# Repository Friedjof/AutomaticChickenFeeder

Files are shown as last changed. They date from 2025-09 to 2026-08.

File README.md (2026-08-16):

# 🐔 Automatic Chicken Feeder

> **Smart, battery-powered feeding system for your chickens with web-based scheduling and deep sleep power management**

An ESP32-C3 based automatic chicken feeder with RTC-scheduled feeding times, web configuration interface, and ultra-low power consumption. Perfect for keeping your chickens fed while you're away!

## 📸 Web Interface

| Schedule Configuration | Manual Control & Settings |
|:---:|:---:|
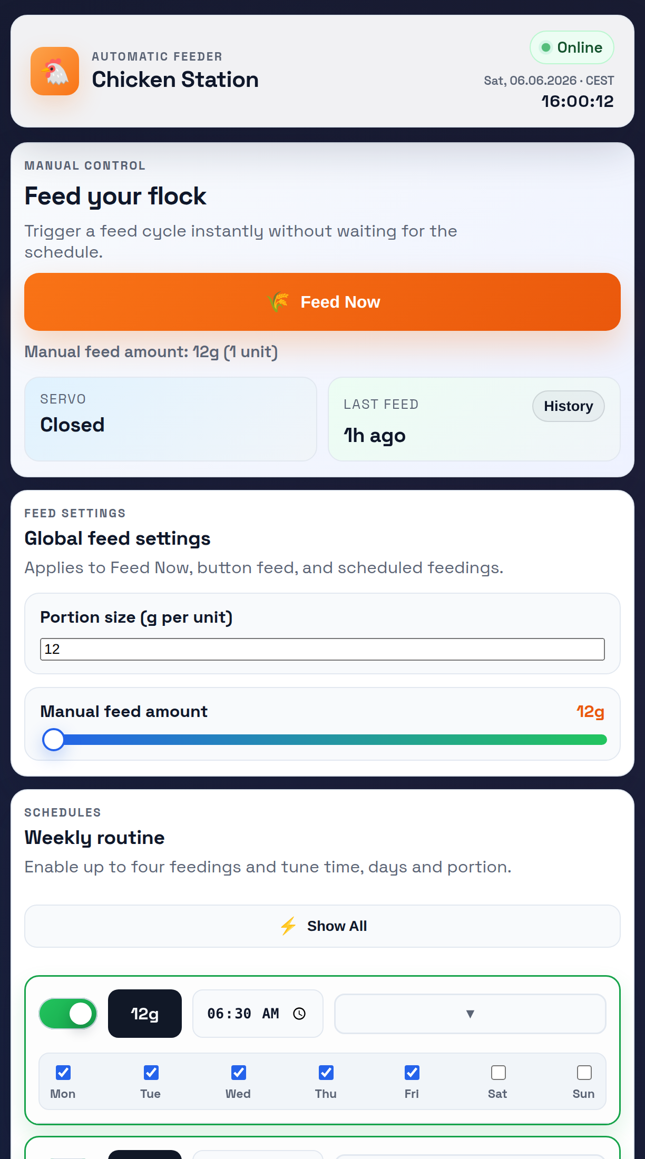
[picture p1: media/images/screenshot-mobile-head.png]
Schedule View
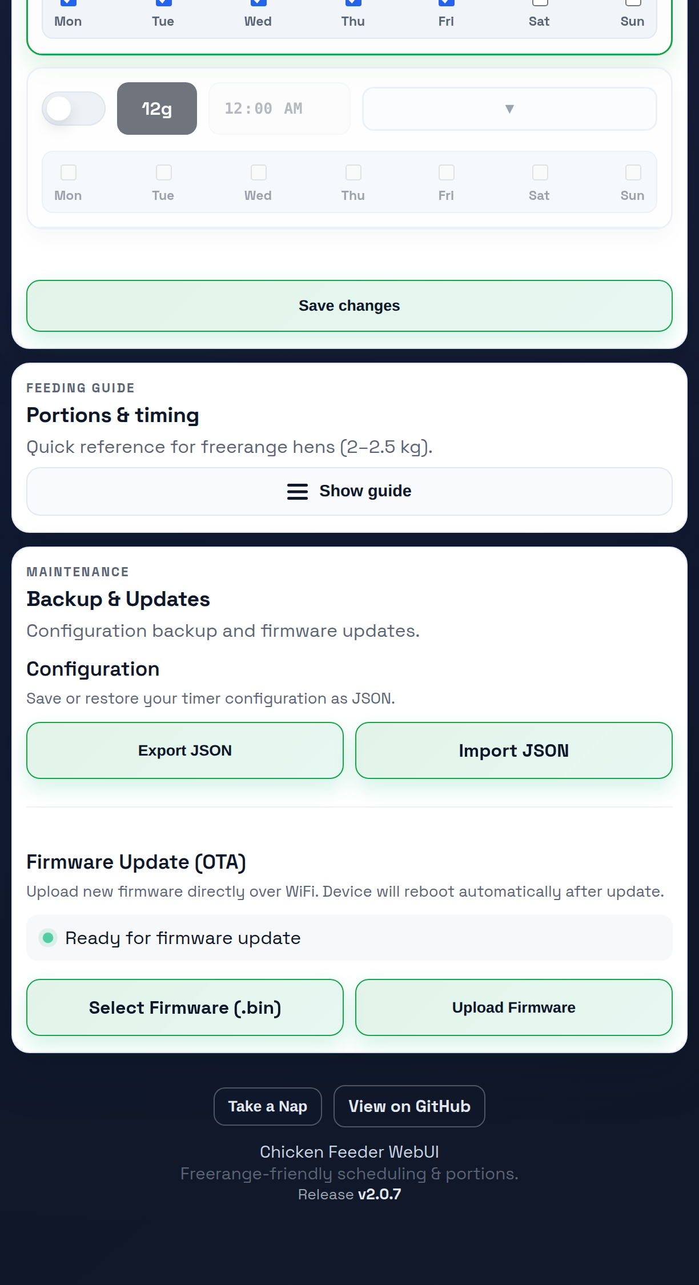
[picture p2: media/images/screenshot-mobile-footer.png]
Manual Control
|  |  |

## 🖨️ 3D Design

| Cross-Section | Animated View | Top View |
|:---:|:---:|:---:|
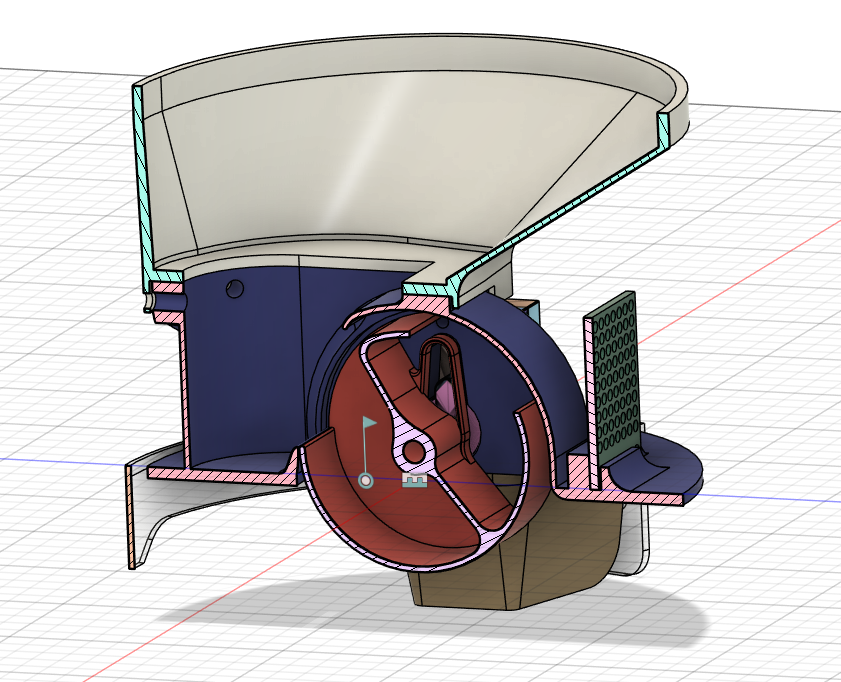
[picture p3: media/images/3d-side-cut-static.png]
Cross-Section
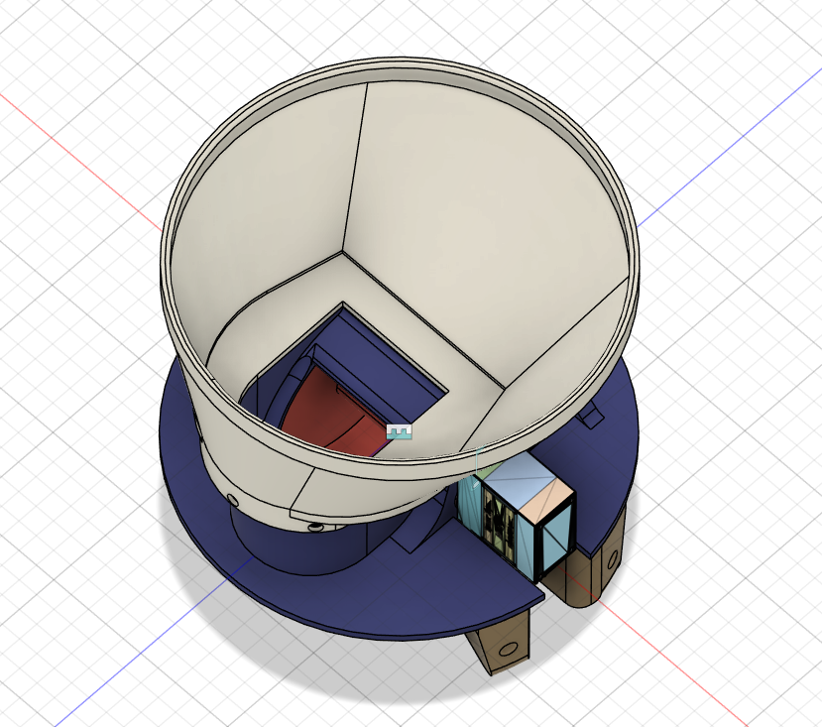
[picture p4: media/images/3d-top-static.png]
Top View
|  | 3D Animation |  |

> **Note:** 3D printable models (.stl files) will be added soon.

## ✨ Features

- 🕐 **RTC-Based Scheduling** - DS3231 external RTC with alarm interrupts for precise feeding times
- 📅 **Flexible Schedules** - Configure up to 6 feeding times with weekday selection (e.g., Mon-Fri only)
- 🌐 **Embedded Web Interface** - Complete configuration via WiFi AP, no SD card needed
- 📱 **Mobile-Optimized UI** - Smart View automatically shows relevant timers on mobile devices
- 🖥️ **Visible Device Clock** - Current device date/time shown in the top bar of the web UI
- 🔋 **Ultra-Low Power** - Deep sleep mode (~10-20µA) with dual wakeup sources
- ⚡ **Smart Power Management** - Automatic sleep after 2 minutes inactivity
- 🎚️ **Configurable Portions** - 1-5 portion units (12g per unit)
- 🔘 **Physical Button Control** - Single/double/long-press for manual operation
- 🕒 **Automatic Time Sync** - Browser syncs time to RTC when the web UI opens
- 🌍 **Timezone Support** - Europe/Berlin with CET/CEST daylight saving handling
- 🔄 **OTA Firmware Updates** - Update firmware over WiFi without USB cable

## 🎮 Button Controls

| Action | Function |
|---|---|
| **Single Click** | Start WiFi AP for configuration |
| **Double Click** | Manual feed (1 portion) |
| **Long Press** | Enter deep sleep immediately |
| **Press while sleeping** | Wake up + start AP mode (after 1s delay) |
| **Hold during boot** | Maintenance mode (optional, keeps WiFi on) |

## 🔧 Hardware Setup

### Components
- **Board:** Seeed Xiao ESP32-C3
- **RTC:** DS3231 external real-time clock module (I2C)
- **Servos:** 2x servo motors (GPIO2, GPIO21)
- **Button:** Push button with pull-up (GPIO4)
- **Power Control:** Transistor for servo power switching (GPIO5)

### GPIO Pin Assignment

| GPIO | Function | Direction | Notes |
|---|---|---|---|
| GPIO2 | Servo 2 | Output | PWM control |
| GPIO3 | RTC INT | Input (PULLUP) | Alarm wakeup |
| GPIO4 | Button | Input (PULLUP) | User input + wakeup |
| GPIO5 | Transistor | Output | Servo power control |
| GPIO10 | Vibration Motor | Output | Transistor-driven, anti-clump shaking |
| GPIO21 | Servo 1 | Output | PWM control |
| I2C SDA | DS3231 | I/O | RTC communication |
| I2C SCL | DS3231 | I/O | RTC communication |

### Power Requirements
- **ESP32-C3:** 3.3V
- **Servos:** 5V with adequate current (500mA+ peak)
- **RTC:** 3.3V or 5V (with built-in level shifting)

## 🚀 Quick Start

### Prerequisites
- PlatformIO Core (`pip install platformio`) or VS Code extension
- Node.js (v18+) for web interface build
- GNU Make
- ESP32-C3 connected via USB

### Build & Flash

**IMPORTANT:** Always use `make build` instead of `pio run` directly!

```bash
# Full build (web UI + firmware)
make build

# Flash to device
make flash

# Flash and monitor serial output
make run

# With specific port
make run 1        # Flash + monitor on /dev/ttyACM1
```

### Why Use the Makefile?

The Makefile automates the complete build pipeline:

1. **Web UI Build** - Runs `npm install` and Vite build
2. **Header Generation** - Converts HTML/CSS/JS to gzipped C headers
3. **Firmware Compilation** - Embeds web files into ESP32 firmware

**Skipping `make` and using `pio run` directly will result in outdated web files!**

### Device Port Management

```bash
# Auto-detect port (single device)
make flash
make monitor

# Specific port (multiple devices)
make flash 2      # Flash to /dev/ttyACM2
make monitor 2    # Monitor /dev/ttyACM2
make run 1        # Flash + monitor on /dev/ttyACM1

# List connected ESP32 devices
make list
```

## ⚙️ Configuration

### Web Interface Setup

1. **Power on the device** or **press button once** to start WiFi AP
2. **Connect to WiFi:** `ChickenFeeder` (no password)
3. **Open browser:** Navigate to `http://192.168.4.1`
4. **Configure schedules:**
   - Set feeding times (HH:MM format)
   - Select weekdays (Mon-Sun)
   - Set portion units (1-5)
   - Enable/disable schedules
5. **Save configuration** - Stored in ESP32 NVS (non-volatile storage)

### Manual Time Sync
Time syncs automatically from your browser when the web UI opens. The device clock shown in the top bar is loaded from the RTC once at startup and then advanced locally in the browser. Initial setup requires opening the web interface once to set the RTC time.

### Config Import/Export
Download or upload your configuration as JSON for backup or transfer to another device.

### OTA Firmware Updates

Update firmware wirelessly without USB connection:

1. **Start WiFi AP:**
   - Press button once (or device wakes from sleep)
   - Connect to WiFi: `ChickenFeeder` (no password)

2. **Open web interface:** Navigate to `http://192.168.4.1`

3. **Upload firmware:**
   - Scroll to "Maintenance" section at bottom
   - Click "Select Firmware (.bin)"
   - Choose your `.bin` file (from `.pio/build/esp32c3/firmware.bin`)
   - Click "Upload Firmware"
   - Wait for progress bar to complete (~10-30 seconds)

4. **Device reboots automatically** with new firmware

**Important:**
- Only upload `.bin` files built for ESP32-C3
- Do not power off during upload
- Configuration data is preserved (stored in NVS)
- Optionally backup your configuration before updating (Export JSON)

## 🔋 Power Management

### Deep Sleep Mode

The system enters deep sleep (~10-20µA) to conserve battery power:

- **After 2 minutes** of inactivity (no button press, no web client)
- **After RTC alarm** feeding completes
- **Manual trigger** via long-press button

### Wakeup Sources

| Source | GPIO | Trigger | Action |
|---|---|---|---|
| **Button** | GPIO4 | LOW | Wake → Wait ~150ms → Start AP |
| **RTC Alarm** | GPIO3 | LOW | Wake → Feed → Sleep |

### Stay-Awake Conditions
- WiFi AP has connected clients
- Feeding operation in progress
- Any button press (resets 2-minute timer)

### Battery Life Estimate

With a 2000mAh battery:
- **Deep sleep 23.5h/day:** ~11 years theoretical maximum
- **Realistic usage (30min active/day):** ~50 days

## 📁 Project Structure

```
AutomaticChickenFeeder/
├── src/
│   └── main.cpp                    # Main application
├── lib/
│   ├── ButtonService/              # Button input handling
│   ├── FeedingService/             # Dual servo control
│   ├── ClockService/               # DS3231 RTC management
│   ├── ConfigService/              # NVS configuration storage
│   ├── SchedulingService/          # Event queue & RTC alarms
│   └── WebService/                 # AsyncWebServer & captive portal
├── web/
│   ├── src/
│   │   ├── app.js                  # Web UI logic
│   │   └── styles.css              # Modern UI styling
│   ├── index.html                  # Main page
│   └── vite.config.js              # Build configuration
├── scripts/
│   └── web-to-header.py            # Converts web files to C headers
├── Makefile                        # Build automation
├── platformio.ini                  # PlatformIO configuration
└── AGENTS.md                       # Development guidelines

```

## 🛠️ Development

### Build Workflow

**After ANY code change (backend OR frontend):**
```bash
make build    # or just: make
```

**Frontend-only changes:**
```bash
make web-headers    # Rebuild web UI headers
pio run             # Compile firmware
```

**Backend-only changes:**
```bash
make build    # Still use make! Ensures web files are current
```

### Creating a Release

**Single command to create and publish a release:**
```bash
make release VERSION=v2.1.0
```

This will automatically:
- Update version in all files
- Rebuild web interface with new version
- Commit, tag, and push to GitHub
- Trigger automated release build

See [docs/RELEASE.md](docs/RELEASE.md) for details.

### Service Architecture

```
main.cpp
├── ButtonService (GPIO4)
│   ├── Single click → Start AP
│   ├── Double click → Manual feed
│   └── Long press → Deep sleep
├── FeedingService (GPIO2, GPIO21, GPIO5)
│   ├── Dual servo control
│   ├── Transistor power switching
│   └── Multi-portion feeding
├── ClockService (I2C @ 0x68)
│   ├── DS3231 RTC time management
│   ├── Timezone conversion (UTC → CET/CEST)
│   └── Alarm programming
├── ConfigService (NVS)
│   ├── 6 schedules storage
│   └── Portion unit configuration
├── SchedulingService
│   ├── Event queue (50 events, 7 days)
│   ├── Weekday mask filtering
│   └── RTC alarm management
└── WebService (WiFi AP)
    ├── AsyncWebServer (port 80)
    ├── Captive portal DNS
    ├── REST API endpoints
    └── Time sync (browser → RTC)
```

## 📚 Documentation

- **[AGENTS.md](AGENTS.md)** - Comprehensive development guidelines and build system documentation
- **[docs/dev.md](docs/dev.md)** - Development setup and troubleshooting

## 🤝 Contributing

1. Fork the repository
2. Create a feature branch
3. Make your changes
4. Test thoroughly (hardware + web interface)
5. Submit a pull request

## 📝 License

This project is open source. See LICENSE file for details.

## 🙏 Acknowledgments

Built with:
- [PlatformIO](https://platformio.org/) - Embedded development platform
- [ESP32Servo](https://github.com/madhephaestus/ESP32Servo) - Servo control library
- [Button2](https://github.com/LennartHennigs/Button2) - Button handling
- [RTClib](https://github.com/adafruit/RTClib) - DS3231 RTC library
- [ESPAsyncWebServer](https://github.com/me-no-dev/ESPAsyncWebServer) - Async web server
- [Vite](https://vitejs.dev/) - Frontend build tool

---

**Made with ❤️ for happy chickens** 🐔

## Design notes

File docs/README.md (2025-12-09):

# Automatic Chicken Feeder

This project is an **ESP32-C3 based automatic chicken feeder** using PlatformIO. It provides button-controlled servo operation to dispense chicken feed on demand.

## Features

- **Button Control**: Single click to trigger feeding cycle
- **Dual Servo System**: Two servos work in sync to open/close the feeding mechanism
- **Simple Operation**: Press button → servos open → 1 second delay → servos close
- **ESP32-C3**: Uses Seeed Xiao ESP32-C3 development board

## Hardware Requirements

- **Seeed Xiao ESP32-C3** development board
- **2x Servo Motors** (connected to GPIO pins 2 and 3)
- **Push Button** (connected to GPIO pin, defined in ButtonService)
- **Power Supply** suitable for servos

## Build & Flash

The Makefile supports convenient port selection for multiple ESP32 devices:

```bash
make                # build only
make flash          # flash with auto-detected port
make flash 1        # flash to /dev/ttyACM1
make monitor        # monitor with auto-detected port  
make monitor 2      # monitor /dev/ttyACM2
make run            # flash + monitor (auto-detect)
make run 1          # flash + monitor on /dev/ttyACM1
make list           # list available ESP32 devices with port numbers
make clean          # clean build artifacts
```

## Project Structure

- `platformio.ini` – ESP32-C3 configuration with Arduino framework
- `src/main.cpp` – Main application logic with button handling
- `lib/ButtonService/` – Button input handling using Button2 library
- `lib/FeedingService/` – Servo control for feeding mechanism
- `lib/WebService/` – (Placeholder for future web interface)
- `Makefile` – Enhanced build system with device port management

## How It Works

1. **Setup**: ButtonService initializes button with click handler, FeedingService attaches servos
2. **Main Loop**: Continuously checks for button presses
3. **Feed Cycle**: On button click → FeedingService.feed() → servos open (180°) → delay 1s → servos close (0°)
4. **Servo Coordination**: Two servos move in opposite directions for synchronized operation

## Dependencies

- `ESP32Servo` (v3.0.9+) - Servo motor control
- `Button2` (v2.5.0+) - Advanced button handling with debouncing

## Pin Configuration

- **Servo 1**: GPIO 3 (SERVO1_PIN)
- **Servo 2**: GPIO 2 (SERVO2_PIN)  
- **Button**: Defined in ButtonService (check ButtonService.hpp for pin)

## Usage

1. Power on the device
2. Press the button to trigger a feeding cycle
3. Servos will open, wait 1 second, then close
4. Repeat as needed for feeding chickens

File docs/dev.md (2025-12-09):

# Developer Notes

- **Toolchain**: PlatformIO + Arduino core for ESP32-C3 using standard espressif32 platform.
- **Hardware**: Seeed Xiao ESP32-C3 development board with 2 servos and button input.
- **Build Targets**: Enhanced Makefile with device port management:
  - `make` / `make build` – compile firmware for ESP32-C3.
  - `make flash` – flash with auto-detected port.
  - `make flash 1` – flash to specific port /dev/ttyACM1.
  - `make monitor` – serial monitor at 115200 baud (auto-detect port).
  - `make monitor 2` – monitor specific port /dev/ttyACM2.
  - `make run` – flash + monitor in one command (auto-detect).
  - `make run 1` – flash + monitor on /dev/ttyACM1.
  - `make list` – list available ESP32 devices with port numbers.
  - `make clean` – remove build artifacts.
- **Dependencies**: 
  - ESP32Servo library (v3.0.9+) for servo motor control
  - Button2 library (v2.5.0+) for advanced button handling
- **Pin Configuration**:
  - Servo 1: GPIO 3 (SERVO1_PIN)
  - Servo 2: GPIO 2 (SERVO2_PIN)
  - Button: Check ButtonService.hpp for pin definition
- **First Run**: If PlatformIO complains about missing Python in `.pio-home/penv`, create it with `python3 -m venv .pio-home/penv` once.

## Code Architecture

- **ButtonService**: Wraps Button2 library, handles single/double/long click events
- **FeedingService**: Controls dual servo system for feed dispensing mechanism
- **WebService**: Placeholder class for future web interface implementation
- **Main Loop**: Simple event-driven architecture with button → servo response

## Current Functionality

The project implements a basic chicken feeder with button-controlled servo operation:
1. Button press triggers feeding cycle
2. Two servos open synchronously (180° and 0° respectively) 
3. 1-second delay for feed dispensing
4. Servos close back to starting positions

This is a functional prototype, not a minimal "hello world" - it provides real chicken feeding capability.

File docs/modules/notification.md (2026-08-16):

# Notification Module (Optional)

> **Status:** Not implemented in the current firmware. This document describes a possible future module — there is no `lib/NotificationService` yet.

The notification module centralises how the feeder communicates alerts to the outside world. It is considered optional because the initial PlatformIO port can run without user-facing buzzers or LEDs, yet the architecture leaves space for future signalling features.

## Purpose
- Provide a single service interface for raising alerts (feeding errors, low battery, RTC issues, maintenance reminders).
- Abstract specific output hardware such as status LEDs, buzzers, or small displays so other services stay decoupled.
- Offer escalation logic (e.g. repeated beeps for unresolved faults) and quiet hours or acknowledgement handling once input buttons confirm an issue.

## Integration
- Receives events from the System Controller (e.g. `FeedCycleStarted`, `FeedCycleFailed`).
- Coordinates with the Power module to ensure notification hardware is powered only when needed.
- Optional bridge to the Web UI for surfacing alerts in the captive portal during active sessions.

## Future Work
- Define concrete output patterns (blink/beep sequences) per event severity.
- Add configuration hooks so farmers can mute or adjust notification intensity.
- Consider logging notifications to storage for troubleshooting once persistent telemetry is added.

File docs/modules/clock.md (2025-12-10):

# Clock Service

## Purpose
The ClockService wraps the DS3231 RTC module, providing accurate timekeeping, alarm management, and browser-based time synchronization.

## Hardware
- **DS3231 RTC**: High-precision I2C RTC with temperature compensation
- **I2C Bus**: SDA/SCL pins (board-specific)
- **Alarm Pin**: Interrupt output (GPIO 3)
- **Battery Backup**: CR2032 maintains time during power loss

## Responsibilities
- Initialize DS3231 via I2C
- Provide current time via `now()`
- Program hardware alarm for scheduled feeds
- Handle alarm interrupts and clear flags
- Sync time from browser timestamps
- Report RTC availability status

## Public API

```cpp
bool begin();                           // Initialize RTC
DateTime now();                         // Get current time
bool setTime(const DateTime &dt);      // Set RTC time
bool setAlarm(const DateTime &dt);     // Program alarm
bool clearAlarm();                      // Disable and clear alarm
bool checkAlarmFlag();                  // Check if alarm triggered
bool isAvailable() const;               // RTC connection status
```

## RTC Initialization

```cpp
bool ClockService::begin()
```

1. Initialize I2C bus
2. Detect DS3231 presence
3. Check if RTC lost power
4. If lost power: mark as requires sync
5. Disable alarm by default
6. Return availability status

## Time Management

### Getting Current Time
```cpp
DateTime now()
```

- Returns current time from DS3231
- DateTime format: year, month, day, hour, minute, second
- Unix timestamp available via `dt.unixtime()`
- Returns invalid DateTime if RTC unavailable

### Setting Time
```cpp
bool setTime(const DateTime &dt)
```

- Writes new time to DS3231
- Called by browser sync endpoint
- Validates DateTime before write
- Returns success/failure

## Alarm Management

### Programming Alarm
```cpp
bool setAlarm(const DateTime &dt)
```

1. Disables existing alarm
2. Calculates alarm registers from DateTime
3. Programs DS3231 Alarm 1
4. Enables alarm interrupt
5. Logs alarm time to serial
6. Returns success/failure

**DS3231 Alarm Capabilities:**
- Alarm 1: Seconds, minutes, hours, day/date
- Alarm 2: Minutes, hours, day/date (not used)
- Single alarm active at a time

### Clearing Alarm
```cpp
bool clearAlarm()
```

1. Clears alarm flag (`rtc.clearAlarm(1)`)
2. Disables alarm (`rtc.disableAlarm(1)`)
3. Logs to serial: "[CLOCK] Alarm cleared"
4. Called when no schedules active

### Checking Alarm Status
```cpp
bool checkAlarmFlag()
```

- Returns `rtc.alarmFired(1)`
- Called in main loop via SchedulingService
- True if alarm interrupt triggered

## Browser Time Sync

Triggered via WebService API: `POST /api/time`

### Sync Flow
1. Browser sends ISO timestamp
2. WebService parses to Unix timestamp
3. ClockService converts to DateTime
4. `setTime()` updates DS3231
5. Logs sync event to serial

### Format
- Input: ISO 8601 string ("2025-01-15T14:30:00Z")
- Converted to DateTime
- Written to DS3231 registers

## Deep Sleep Integration

### Before Sleep
- RTC alarm remains programmed in DS3231 hardware
- DS3231 maintains time on battery backup
- Alarm pin stays configured as interrupt source

### On Wake
- ESP32 wakes from GPIO interrupt (RTC_INT_PIN)
- SchedulingService calls `checkAlarmFlag()`
- ClockService confirms alarm triggered
- Alarm cleared via `clearAlarm()`

## Integration Points

### SchedulingService
- Calls `now()` for event generation
- Programs alarms via `setAlarm()`
- Checks alarm status via `checkAlarmFlag()`
- Clears alarms via `clearAlarm()`

### FeedingService
- Gets timestamps for feed history
- Calls `now()` via `recordFeedEvent()`

### WebService
- Receives browser time sync requests
- Formats DateTime to ISO 8601 strings
- Returns RTC status in API responses

### Main Application
- Calls `begin()` during setup
- Logs availability status

## Error Handling

### RTC Unavailable
- `begin()` returns false
- `available` flag set to false
- All operations return failure
- System continues without RTC (no scheduled feeds)
- Logged as "[WARN] DS3231 RTC not available"

### Lost Power
- Detected during `begin()`
- Logged as "[CLOCK] RTC lost power, time may be invalid"
- Requires browser sync to restore accurate time

### Invalid DateTime
- Validation before RTC writes
- Returns false on invalid input
- Logs error to serial

## Logging
All operations log to serial with `[CLOCK]` prefix:
- Initialization status
- Lost power detection
- Time sync events
- Alarm programming
- Alarm clearing
- Error conditions

## Testing

### Manual Testing
1. Power cycle device → check for lost power detection
2. Set alarm 2 minutes in future via schedule
3. Monitor serial for alarm programming
4. Wait for alarm trigger
5. Verify alarm flag set and cleared

### Browser Sync Testing
1. Open web UI
2. Monitor serial for sync logs
3. Verify time matches browser
4. Check RTC persists after power cycle

### Alarm Testing
1. Program alarm via SchedulingService
2. Enter deep sleep
3. Wake on RTC alarm
4. Verify alarm flag cleared
5. Check next alarm programmed

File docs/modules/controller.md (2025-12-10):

# Main Controller (main.cpp)

## Purpose
The main.cpp file coordinates all services, manages the application lifecycle, handles wake/sleep logic, and implements the main loop.

## Architecture
Simple procedural design with direct service instantiation:
- No abstract interfaces or event bus
- Services communicate via direct method calls
- State managed through function calls and flags

## Services

### Instantiation
```cpp
ButtonService buttonService;
FeedingService feedingService;
ClockService clockService;
ConfigService configService;
SchedulingService schedulingService(configService, clockService, feedingService);
WebService webService(configService, clockService, feedingService, schedulingService);
```

### Initialization Order (setup())
1. **ConfigService**: Initialize NVS, load settings
2. **ClockService**: Initialize RTC, check time validity
3. **Feed History**: Load from NVS into FeedingService
4. **ButtonService**: Setup GPIO, attach handlers
5. **FeedingService**: Configure servo pins, set clock reference
6. **SchedulingService**: Generate events, program first alarm
7. **WebService**: Prepare server (doesn't start until AP active)

## Hardware Configuration

### Pin Definitions
```cpp
#define RTC_INT_PIN 3      // DS3231 alarm interrupt
#define BUTTON_PIN 4       // User button
#define SERVO1_PIN 21      // Dispenser servo 1
#define SERVO2_PIN 2       // Dispenser servo 2
#define TRANSISTOR_PIN 5   // Servo power control
```

### Wake Sources
- **RTC Alarm**: GPIO 3 (scheduled feeds)
- **Button**: GPIO 4 (manual control, AP activation)

## State Flags

```cpp
bool wokeFromRtcAlarm = false;   // Woke from scheduled alarm
bool wokeFromButton = false;      // Woke from button press
unsigned long lastActivityMillis; // Last user/system activity
unsigned long ignoreButtonUntil;  // Button debounce after wake
```

## Boot Sequence

### Wake Cause Detection
```cpp
esp_sleep_wakeup_cause_t wakeupReason = esp_sleep_get_wakeup_cause();
uint64_t gpioStatus = esp_sleep_get_gpio_wakeup_status();
```

**Wake Reasons:**
- `ESP_SLEEP_WAKEUP_GPIO`: RTC alarm or button
- Other: Power-on reset or unknown

### Maintenance Mode
- Hold button during boot
- Logged as `[MAINTENANCE]`
- Features:
  - Persistent AP (no timeout)
  - OTA updates enabled
  - No automatic sleep
  - Infinite loop serving web UI

### Normal Boot Flow
1. Detect wake cause
2. Initialize all services
3. Load feed history
4. Handle wake-specific actions:
   - **RTC Alarm**: Process due schedules immediately
   - **Button**: Start AP after 2s delay
5. Enter main loop

## Main Loop

```cpp
void loop() {
    buttonService.loop();
    feedingService.update();
    webService.update();
    schedulingService.update();
    handleSleepLogic();
}
```

### Service Updates
- **ButtonService**: Poll button state, trigger callbacks
- **FeedingService**: Advance state machine, complete feeds
- **WebService**: Process DNS, check AP timeout
- **SchedulingService**: Check RTC alarm flag

### Sleep Logic
```cpp
void handleSleepLogic()
```

**Conditions preventing sleep:**
- Feeding in progress
- AP active
- Recent activity (< 2 minutes)

**Automatic sleep triggers:**
- RTC alarm completed (return to sleep immediately)
- Inactivity timeout (2 minutes)

## Button Handlers

### Single Click
```cpp
void simpleClickHandler(Button2 &btn)
```

- Starts AP mode
- Resets activity timer
- 2-second ignore window after wake

### Double Click
```cpp
void doubleClickHandler(Button2 &btn)
```

- Triggers manual feed (1 portion)
- Resets activity timer
- 2-second ignore window after wake

### Long Press
```cpp
void longClickHandler(Button2 &btn)
```

- Enters deep sleep immediately
- No ignore window (always active)

## Deep Sleep Management

### Entering Sleep
```cpp
void enterDeepSleep(const char* reason)
```

1. Save feed history to NVS
2. Stop AP if active
3. Configure wake sources (RTC + Button)
4. Enable GPIO wake on LOW signal
5. Log reason and enter deep sleep

**Wake Mask:**
```cpp
const uint64_t wakeMask = (1ULL << RTC_INT_PIN) | (1ULL << BUTTON_PIN);
esp_deep_sleep_enable_gpio_wakeup(wakeMask, ESP_GPIO_WAKEUP_GPIO_LOW);
```

### Sleep Triggers
- "RTC alarm handled" (after feed completed)
- "Inactivity timeout" (2 minutes idle)
- "Manual long press" (user requested)
- "Remote request" (via WebService)

## Activity Tracking

### Mark Activity
```cpp
void markActivity()
```

- Updates `lastActivityMillis`
- Called on:
  - Button presses
  - Feeding operations
  - Web UI interactions (via WebService)

### Inactivity Timeout
- `INACTIVITY_SLEEP_MS`: 120000 (2 minutes)
- Compared against max of `lastActivityMillis` and web client activity
- Triggers automatic sleep

## Feed History Persistence

### Load (setup)
```cpp
FeedHistoryEntry history[MAX_FEED_HISTORY];
uint8_t historyCount = configService.loadFeedHistory(history, MAX_FEED_HISTORY);
feedingService.loadFeedHistory(history, historyCount);
```

### Save (before sleep)
```cpp
configService.saveFeedHistory(feedingService.getFeedHistory(),
                               feedingService.getFeedHistoryCount());
```

## Power Management Strategy

### Active Time Minimization
- Sleep between scheduled feeds
- AP only active when needed
- Servo power only during dispense
- WiFi disabled in sleep

### Wake/Sleep Cycle
1. **Wake** (RTC or button)
2. **Execute** (feed or serve UI)
3. **Sleep** (automatic after completion)

Typical cycle: <30 seconds active, hours sleeping

## Error Handling

### Service Init Failures
- Logged to serial with `[ERROR]` prefix
- System continues with reduced functionality
- Example: RTC unavailable → no scheduled feeds, manual still works

### Watchdog
- No explicit watchdog (relies on ESP32 default)
- Feeding timeout prevents servo lockup
- AP timeout prevents battery drain

## Logging

All major events logged to serial (115200 baud):
- `[INFO]`: Normal operations
- `[WARN]`: Recoverable issues
- `[ERROR]`: Critical failures
- `[DEBUG]`: Detailed state info
- Service-specific: `[BUTTON]`, `[SCHED]`, `[WEB]`, `[CLOCK]`, `[CONFIG]`

## Testing

### Boot Testing
1. Power on → cold boot
2. Hold button → maintenance mode
3. RTC wake → alarm execution
4. Button wake → AP activation

### Sleep Testing
1. Manual feed → auto sleep after 2 min
2. Long press → immediate sleep
3. RTC alarm → execute and return to sleep
4. AP timeout → auto sleep after 60s

### Integration Testing
1. Schedule feed → verify RTC alarm → wake and feed
2. Manual feed → verify history saved
3. Config change → verify alarm reprogrammed
4. Factory reset → verify defaults restored

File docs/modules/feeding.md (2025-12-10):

# Feeding Service

## Purpose
The FeedingService controls the dual-servo dispensing mechanism. It manages the complete feed cycle including power control, servo movement, timing sequences, and feed event tracking.

## Hardware
- **ESP32-C3** (Seeed XIAO ESP32C3)
- **Servo 1 & 2**: Controlled via ESP32Servo library
- **Transistor**: MOSFET for servo power management (GPIO 5)
- **DS3231 RTC**: For timestamp tracking

## Responsibilities
- Execute feed cycles with configurable portion counts (1-5 units)
- Manage servo power via transistor to minimize energy consumption
- Implement state machine for deterministic servo sequencing
- Track feed events with timestamps for history
- Provide feed status to other services

## State Machine

### States
1. **IDLE**: Servos powered down, waiting for feed request
2. **POWER_ON**: Transistor enabled, waiting for servo voltage stabilization
3. **ATTACH_SERVOS**: Servos attached to PWM pins
4. **SERVO_READY**: Servos ready, preparing for movement
5. **MOVING**: Servos executing open/close sequence
6. **DETACH_SERVOS**: Servos detached from PWM
7. **POWER_OFF**: Transistor disabled, servos unpowered
8. **FEED_WAITING**: Waiting between open/close cycles for multi-portion feeds

### Timing Constants
- `POWER_ON_DELAY`: 100ms - Servo power stabilization
- `SERVO_ATTACH_DELAY`: 100ms - Time after attach before movement
- `SERVO_MOVE_TIME`: 620ms - Duration for servo movement completion
- `FEED_WAIT_TIME`: 1000ms - Delay between open and close

## Feed Cycle Flow

### Single Portion
1. User/Timer triggers `feed(1)`
2. State: IDLE → POWER_ON (enable transistor)
3. State: POWER_ON → ATTACH_SERVOS (attach servos at 100ms)
4. State: ATTACH_SERVOS → SERVO_READY (servos write target position immediately)
5. State: SERVO_READY → MOVING (wait for stabilization)
6. State: MOVING → DETACH_SERVOS (after 620ms movement time)
7. State: DETACH_SERVOS → POWER_OFF (detach servos)
8. State: POWER_OFF → IDLE (disable transistor, record feed event)

### Multiple Portions
For `feed(count > 1)`, the cycle repeats:
- Open gate → Wait → Close gate → Wait → Open gate (next portion)
- After final portion, system returns to IDLE
- Single feed event recorded with total portion count

## Feed History Tracking

### Recording
- Every feed completion calls `recordFeedEvent()`
- Stores: Unix timestamp + portion_units
- Maintains ring buffer of last 10 feeds in RAM
- Persisted to NVS before deep sleep

### Storage
- Ring buffer: `FeedHistoryEntry feedHistory[10]`
- Tracked via: `feedHistoryCount` and `feedHistoryIndex`
- Circular overwrite of oldest entry when full

## Public API

```cpp
void feed(uint8_t count = 1);              // Trigger feed with 1-5 portions
void update();                              // Must be called in loop()
bool isFeeding();                           // Check if feed in progress
uint8_t getPosition();                      // Get current servo position (0-180)
uint32_t getLastFeedTimestamp();            // Unix timestamp of last feed

// Feed history management
void addFeedToHistory(uint32_t timestamp, uint8_t portionUnits);
uint8_t getFeedHistoryCount() const;
const FeedHistoryEntry* getFeedHistory() const;
void loadFeedHistory(const FeedHistoryEntry* history, uint8_t count);
void clearFeedHistory();

void setClockService(ClockService* clock);  // Required for timestamps
```

## Servo Configuration
- **Servo1**: Inverted position `SERVO_MAX_ANGLE - targetPosition`
- **Servo2**: Direct position `targetPosition`
- **Range**: 0° (closed) to 180° (open)
- **PWM Range**: 500-2400μs

## Power Management
- Servos only powered during active feed cycles
- Transistor (GPIO 5) controls power rail
- Automatic power-off after each cycle completes
- Prevents unnecessary battery drain

## Integration Points

### ClockService
- Required for timestamp generation
- Set via `setClockService(ClockService*)` during setup
- Used by `recordFeedEvent()` to get current time

### ConfigService
- Provides portion unit grams configuration
- Loads/saves feed history to NVS

### SchedulingService
- Calls `feed(portionUnits)` when scheduled event triggers
- Monitors `isFeeding()` to prevent sleep during operation

### WebService
- Exposes feed history via `/api/status/history`
- Triggers manual feeds via `/api/feed` endpoint

## Safety Features
- Single feed request guard: ignores requests while feeding
- Portion count validation: clamped to 1-5 range
- State machine prevents power glitches
- Servo detach before power-off prevents brown-out

## Testing
- Manual feed via double-click button
- API endpoint: `POST /api/feed`
- Monitor serial output for state transitions
- Verify feed history via `GET /api/status/history?limit=10`

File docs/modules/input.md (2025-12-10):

# Button Service (Input)

## Purpose
The ButtonService handles the single physical button interface, providing debounced input detection and multi-gesture recognition (single click, double click, long press).

## Hardware
- **Button Pin**: GPIO 4
- **Type**: Active-LOW with internal pull-up
- **Library**: Button2 (gesture recognition)

## Responsibilities
- Initialize button GPIO with pull-up
- Detect button gestures (single, double, long press)
- Provide callback registration for main application
- Handle button debouncing automatically
- Support wake-from-sleep button handling

## Button Gestures

### Single Click
- **Action**: Start WiFi Access Point
- **Use Case**: Open web UI for configuration
- **Callback**: `setSimpleClickHandler()`
- **Debounce**: 2-second ignore window after wake

### Double Click
- **Action**: Trigger manual feed (1 portion)
- **Use Case**: Quick feeding without UI
- **Callback**: `setDoubleClickHandler()`
- **Debounce**: 2-second ignore window after wake

### Long Press
- **Action**: Enter deep sleep immediately
- **Use Case**: Manual power down
- **Callback**: `setLongClickHandler()`
- **No Debounce**: Always active (override safety)

## Public API

```cpp
void begin();                                         // Initialize button
void loop();                                          // Must be called in loop()
void setSimpleClickHandler(void (*callback)(Button2&));
void setDoubleClickHandler(void (*callback)(Button2&));
void setLongClickHandler(void (*callback)(Button2&));
```

## Initialization

```cpp
void ButtonService::begin()
```

1. Configure Button2 library
2. Set GPIO 4 as input with pull-up
3. Register click handlers
4. Log initialization

## Main Loop

```cpp
void ButtonService::loop()
```

- Calls `button.loop()` from Button2 library
- Handles debouncing and gesture detection
- Triggers registered callbacks on events

## Wake Handling

### Wake Detection
In main.cpp:
```cpp
if (wokeFromButton) {
    ignoreButtonUntil = millis() + 2000;  // 2-second ignore window
}
```

### Button Ignore Logic
```cpp
if (millis() < ignoreButtonUntil) {
    Serial.println("[BUTTON] Ignoring click (too soon after wakeup)");
    return;  // But still mark activity
}
```

**Purpose**: Prevent consuming the wakeup button press as an action

## Callback Implementations (main.cpp)

### Single Click Handler
```cpp
void simpleClickHandler(Button2 &btn) {
    markActivity();
    if (millis() < ignoreButtonUntil) return;

    Serial.println("[BUTTON] Single click - Starting AP mode");
    webService.startAP("ChickenFeeder", "");
}
```

### Double Click Handler
```cpp
void doubleClickHandler(Button2 &btn) {
    markActivity();
    if (millis() < ignoreButtonUntil) return;

    Serial.println("[BUTTON] Double click - Manual feed");
    feedingService.feed(1);
}
```

### Long Press Handler
```cpp
void longClickHandler(Button2 &btn) {
    Serial.println("[BUTTON] Long click - Entering deep sleep");
    enterDeepSleep("Manual long press");
}
```

**Note**: Long press has no ignore window - always processes

## Maintenance Mode Detection

In main.cpp setup():
```cpp
pinMode(BUTTON_PIN, INPUT_PULLUP);
delay(50);  // Debounce
bool maintenanceModeRequested = (digitalRead(BUTTON_PIN) == LOW);
```

If button held during boot:
- Enter maintenance mode
- Persistent AP with OTA enabled
- No automatic sleep
- Infinite loop serving web UI

## Integration Points

### Main Application
- Registers callback handlers during setup
- Implements ignore window logic
- Calls `loop()` in main loop
- Marks activity on button events

### WebService
- Started via single-click callback
- AP mode activated for configuration

### FeedingService
- Triggered via double-click callback
- Executes 1-portion feed

### Power Management
- Long press triggers immediate deep sleep
- Button wake prevents timeout sleep
- Activity tracking resets sleep timer

## Button2 Library Features

### Automatic Handling
- Hardware debouncing
- Click counting (single/double)
- Long press timing
- Event callbacks

### Timing Thresholds
- Click timeout: ~400ms
- Long press threshold: ~1000ms
- Double click window: ~400ms

(Library defaults, not explicitly configured)

## Wake Source Configuration

In main.cpp before sleep:
```cpp
const uint64_t wakeMask = (1ULL << RTC_INT_PIN) | (1ULL << BUTTON_PIN);
esp_deep_sleep_enable_gpio_wakeup(wakeMask, ESP_GPIO_WAKEUP_GPIO_LOW);
```

**Wake Trigger**: LOW signal (button pressed)

## Safety Features

### Click Debouncing
- Hardware debounce via Button2
- Software ignore window after wake
- Prevents accidental double-triggers

### Activity Marking
- All button events mark activity
- Resets sleep timeout
- Keeps system awake during interaction

### Long Press Override
- No ignore window on long press
- Allows emergency sleep from any state
- User can force sleep if system stuck

## Testing

### Gesture Testing
1. Single click → verify AP starts
2. Double click → verify feed triggers
3. Long press → verify immediate sleep
4. Test ignore window: press immediately after wake

### Wake Testing
1. Sleep device
2. Press button → verify wake
3. Verify 2-second ignore window active
4. Test that third press triggers action

### Maintenance Mode
1. Hold button during power-on
2. Verify persistent AP starts
3. Check maintenance mode logs

## Logging
All button events logged with `[BUTTON]` prefix:
- Click type (single/double/long)
- Action taken
- Ignore window status
- Activity marking

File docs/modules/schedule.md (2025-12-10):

# Scheduling Service

## Purpose
The SchedulingService manages the feeding schedule by generating timer events from configured schedules, programming RTC alarms, and triggering feeds at the appropriate times.

## Responsibilities
- Generate timer events from enabled schedules
- Program DS3231 RTC alarm for next due event
- Handle RTC alarm interrupts and execute feeds
- Regenerate events when configuration changes
- Maintain event queue for upcoming feeds

## Hardware
- **DS3231 RTC**: Hardware alarm capability
- **RTC Interrupt Pin** (GPIO 3): Wakes ESP32 from deep sleep
- Event generation covers next 7 days

## Data Structures

### Timer Event
```cpp
struct TimerEvent {
    DateTime timestamp;    // When feed should occur
    uint8_t scheduleId;   // Which schedule triggered this (1-6)
    uint8_t portionUnits; // How many portions to dispense
    bool valid;           // Event is active
};
```

### Schedule Entry
```cpp
struct Schedule {
    uint8_t id;              // 1-6
    bool enabled;            // Active/inactive
    char time[6];            // "HH:MM" format
    uint8_t weekday_mask;    // Bit 0=Sunday, 6=Saturday
    uint8_t portion_units;   // 1-5 units per feed
};
```

## Public API

```cpp
void begin();              // Initialize, generate events, program first alarm
void update();             // Check for RTC alarm flag (call in loop)
void onConfigChanged();    // Regenerate events after schedule changes
void checkAlarm();         // Handle alarm trigger, execute due feeds
```

## Event Generation

### Algorithm
1. Load all 6 schedules from ConfigService
2. For each enabled schedule:
   - Calculate next occurrence starting from now
   - Generate occurrences for next 7 days
   - Add to timer event queue (max 50 events)
3. Sort events by timestamp
4. Program RTC alarm for earliest future event

### Next Occurrence Calculation
```cpp
DateTime getNextOccurrence(const Schedule &schedule, const DateTime &from)
```

- Parses time from "HH:MM" format
- Checks if today's occurrence is still future
- Iterates through next 7 days to find matching weekday
- 60-second grace window for events just triggered
- Returns invalid DateTime if no match found

### Weekday Matching
```cpp
bool isActiveOnWeekday(uint8_t weekdayMask, uint8_t weekday)
```

- weekday: 0=Sunday, 1=Monday, ..., 6=Saturday
- weekdayMask: bit field (bit 0=Sunday, bit 6=Saturday)
- Returns true if corresponding bit is set

**Example:** weekdayMask = 62 (0b0111110) = Monday–Friday

## RTC Alarm Management

### Programming Next Alarm
```cpp
void programNextAlarm()
```

1. Find next future event from queue
2. If no events exist:
   - Clear RTC alarm
   - Log "alarm disabled"
   - Return
3. Program RTC with event timestamp via ClockService
4. Log scheduled event details

### Alarm Handling
```cpp
void checkAlarm()
```

Called when RTC alarm triggers:
1. Clear RTC alarm flag via ClockService
2. Find all due events (timestamp ≤ now)
3. For each due event:
   - Call `handleTimerEvent()`
   - Mark event as invalid
4. Program next alarm

### Feed Execution
```cpp
void handleTimerEvent(TimerEvent &event)
```

- Triggers `feedingService.feed(event.portionUnits)`
- Logs schedule ID and portion count
- FeedingService handles actual dispensing

## Configuration Change Flow

When schedules are updated via API:
1. WebService receives POST to `/api/config`
2. ConfigService saves new schedules to NVS
3. WebService calls `schedulingService.onConfigChanged()`
4. SchedulingService:
   - Regenerates all timer events
   - Programs next alarm
   - Old events are discarded

## Integration Points

### ConfigService
- Loads schedules via `loadAllSchedules()`
- Called once at `begin()` and on config changes

### ClockService
- Gets current time via `now()`
- Programs alarm via `setAlarm(DateTime)`
- Clears alarm via `clearAlarm()`
- Checks alarm flag via `checkAlarmFlag()` and `alarmFired()`

### FeedingService
- Triggers feeds via `feed(portionUnits)`
- Monitors `isFeeding()` to track completion

### Main Application
- Calls `update()` in main loop
- Calls `checkAlarm()` on RTC wake
- Prevents sleep while feeding active

## Deep Sleep Integration

### Before Sleep
- Current timer events remain in RAM (lost during deep sleep)
- RTC alarm stays programmed in DS3231 hardware
- DS3231 maintains time and triggers interrupt

### On Wake (RTC Alarm)
1. ESP32 wakes from GPIO interrupt (RTC_INT_PIN)
2. Main calls `schedulingService.checkAlarm()`
3. Due events are executed
4. Events regenerated from schedules
5. Next alarm programmed
6. System returns to sleep

## Event Queue Management

### Constants
- `MAX_TIMER_EVENTS`: 50 events maximum
- Coverage: 7 days forward
- Auto-regeneration on config change

### Limits
- 6 schedules × 7 days = up to 42 events per schedule
- Typical usage: 3-5 active schedules = 21-35 events

## Error Handling

### No Valid Events
- `programNextAlarm()` disables RTC alarm
- System stays in deep sleep until button wake
- Logged as "[SCHED] No future events - alarm disabled"

### Schedule Load Failure
- Logs error to serial
- Returns without programming alarm
- System remains functional with previous events

### Invalid Time/Weekday
- `getNextOccurrence()` returns invalid DateTime
- Event not added to queue
- Continues with other schedules

## Testing

### Manual Testing
1. Enable schedule via web UI
2. Set time 2 minutes in future
3. Monitor serial: "[SCHED] Added event: Schedule X at YYYY-MM-DD HH:MM"
4. Wait for alarm trigger
5. Verify feed execution

### Schedule Validation
- Test weekday masks: single day, range, all days
- Test time wrapping: late night → next morning
- Test disabled schedules: should not generate events
- Test multiple schedules at same time

### Alarm Programming
- Verify alarm clears when all schedules disabled
- Verify alarm updates on config change
- Test deep sleep wake via RTC alarm

## Logging
All operations log to serial with `[SCHED]` prefix:
- Event generation count
- Individual event timestamps
- Alarm programming confirmations
- Alarm trigger notifications
- Feed execution details

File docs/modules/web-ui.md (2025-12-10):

# Web Service & UI

## Purpose
The WebService provides a captive portal interface for configuration and manual control. It hosts a responsive web UI and REST API that runs only when the WiFi Access Point is active.

## Architecture
- **AsyncWebServer**: ESPAsyncWebServer library
- **DNSServer**: Captive portal DNS redirect
- **Static Assets**: Embedded in firmware via `generated/web_files.h`
- **AP Mode Only**: WiFi disabled during normal operation

## Hardware
- **ESP32-C3** WiFi radio
- **AP IP**: 192.168.4.1
- **DNS Port**: 53

## Responsibilities
- Host captive portal Access Point
- Serve static web UI assets (HTML, CSS, JS)
- Provide REST API for config and control
- Handle OTA firmware updates
- Manage AP lifecycle and timeouts

## Access Point Management

### Starting AP
```cpp
void startAP(const char* ssid = "ChickenFeeder", const char* password = "");
```

Triggered by:
- Button single-click (GPIO 4)
- Wake from button during sleep
- Maintenance mode (button held during boot)

### AP Timeout Logic
- **No client connected**: 60 seconds timeout
- **Client connected**: Stays active indefinitely
- **Inactivity**: User must disconnect to trigger sleep

### Stopping AP
```cpp
void stopAP();
```

Automatic shutdown:
- Timeout expired
- Sleep requested
- Maintenance mode exited

## REST API Endpoints

### Status & Telemetry
**GET** `/api/status`
```json
{
  "success": true,
  "data": {
    "isOnline": true,
    "isFeeding": false,
    "servoPosition": "Closed",
    "lastFeedTime": "2025-01-15T14:30:00Z",
    "totalFedToday": 0
  }
}
```

**GET** `/api/status/history?limit=10`
```json
{
  "success": true,
  "data": {
    "feeds": [
      {
        "timestamp": "2025-01-15T14:30:00Z",
        "portion": 36
      }
    ]
  }
}
```

### Configuration
**GET** `/api/config`
```json
{
  "success": true,
  "data": {
    "version": 1,
    "portion_unit_grams": 12,
    "schedules": [
      {
        "id": 1,
        "enabled": true,
        "time": "06:30",
        "weekday_mask": 62,
        "portion_units": 2
      }
    ]
  }
}
```

**POST** `/api/config` (Content-Type: application/json)
```json
{
  "schedules": [
    {
      "id": 1,
      "enabled": true,
      "time": "06:30",
      "weekday_mask": 62,
      "portion_units": 2
    }
  ],
  "portion_unit_grams": 12
}
```

### Manual Feed
**POST** `/api/feed`
```json
{
  "success": true,
  "message": "Feed cycle started"
}
```

### Time Sync
**POST** `/api/time` (Content-Type: application/json)
```json
{
  "timestamp": "2025-01-15T14:30:00Z"
}
```

Response:
```json
{
  "success": true,
  "message": "RTC synchronized"
}
```

### Power Management
**POST** `/api/power/sleep`
```json
{
  "success": true,
  "message": "Entering sleep mode"
}
```

### Factory Reset
**POST** `/api/config/reset`
```json
{
  "success": true,
  "message": "Configuration reset to defaults"
}
```

### OTA Updates
**GET** `/api/ota/status`
```json
{
  "success": true,
  "version": "2.0.3",
  "available": true
}
```

**POST** `/api/ota/update` (multipart/form-data)
- Upload `.bin` firmware file
- Performs flash update
- Reboots on success

## Web UI Features

### Dashboard
- System status cards
- Last feed timestamp
- Next scheduled feed
- Manual feed button
- Schedule management link

### Schedule Editor
- 6 configurable schedule slots
- Time picker (HH:MM)
- Weekday selector (7 toggles)
- Portion units dropdown (1-5)
- Enable/disable toggle per slot
- Save button triggers `/api/config` POST

### Feed History (NEW)
- Last 10 feed events
- Timestamp display
- Portion size in grams
- Collapsible on mobile

### Settings
- Portion unit grams configuration
- Factory reset button
- OTA firmware upload
- "Take a Nap" (sleep) button

## Captive Portal

### DNS Redirection
All DNS queries redirect to 192.168.4.1:
- Android: `/generate_204`
- iOS: `/hotspot-detect.html`
- Windows: `/connecttest.txt`

All redirect to `/` (index.html)

### Static File Serving
Assets embedded in firmware:
- `index.html`: Main UI
- `app.js`: Application logic
- `style.css`: Responsive styles
- `mock/api.js`: Offline development mock

Files served with proper MIME types via AsyncWebServer.

## Maintenance Mode

### Activation
Hold button (GPIO 4) during boot to enter maintenance mode.

### Features
- Persistent AP (no timeout)
- Open WiFi (no password): SSID "ChickenFeeder"
- OTA updates enabled
- No automatic sleep
- Serial logging: `[MAINTENANCE]` prefix

### Exit
Power cycle or firmware upload required.

## Integration Points

### ConfigService
- Loads/saves schedules
- Provides portion unit grams
- Handles factory reset

### SchedulingService
- Calls `onConfigChanged()` after config save
- Triggers event regeneration and alarm update

### FeedingService
- Triggers manual feeds
- Checks `isFeeding()` status
- Retrieves last feed timestamp
- Provides feed history data

### ClockService
- Syncs RTC from browser time
- Formats timestamps for API responses

### Main Application
- Receives sleep callback via `setSleepCallback()`
- Monitors AP activity via `isAPActive()`
- Tracks client activity via `getLastClientActivity()`

## Security
- **No authentication**: Physical access required (connect to AP)
- **Optional password**: Can set WiFi password in `startAP()`
- **Local only**: No internet connectivity
- **Temporary**: AP times out automatically

## Client Activity Tracking
```cpp
uint32_t getLastClientActivity() const;
```

Updated on every API request via `updateClientActivity()`.
Used by main application to prevent sleep during active sessions.

## Error Handling
- Invalid JSON: 400 Bad Request
- Feed while feeding: 400 with error message
- Portion validation: Rejects <1 or >5 units
- Serial logging: `[WEB]` prefix for all operations

## Testing
1. Connect to "ChickenFeeder" WiFi
2. Browser should auto-open captive portal
3. Manual: Navigate to http://192.168.4.1
4. Test all API endpoints via UI
5. Monitor serial output for `[WEB]` logs
6. Verify AP timeout after 60s with no client

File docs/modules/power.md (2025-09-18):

# Power Service

## Purpose
The power service manages the device’s power modes. It coordinates WiFi activation, servo power rails, and deep-sleep transitions so the feeder runs on minimal energy while still waking for scheduled tasks or user interactions.

## Responsibilities
- Configure sleep sources (RTC alarm, button GPIOs) and enter/exit deep sleep on demand.
- Switch WiFi SoftAP on/off based on controller or Web UI requests.
- Control servo power enable pins/FETs to reduce standby consumption.
- Track battery/voltage readings if hardware provides sensors (optional integration with NotificationService).
- Expose status flags (`wifiActive`, `servoPowerActive`, `sleepPending`) for diagnostics.

## Key APIs
- `enableWifiAp()` / `disableWifiAp()` – toggles SoftAP; internally uses ESP-IDF WiFi APIs and coordinate with WebUiService.
- `setServoPower(bool on)` – drives GPIO controlling servo rail.
- `prepareDeepSleep(WakeSources sources)` – configures wake-up triggers.
- `enterDeepSleep()` – final call before MCU sleeps; ensures WiFi and unnecessary peripherals are off.
- `onWake()` – reinitialise power domains if needed (e.g. re-enable I2C power).

## Integration
- **SystemController**: instructs PowerService to enter deep sleep when conditions met; queries ability to sleep (e.g. `canSleep()` or checks whether WiFi session active).
- **WebUiService**: requests WiFi AP when user opens captive portal; notifies when session ends.
- **FeedingService**: asks for servo power while dispensing.
- **NotificationService**: may need temporary power during alerts (short beeps/LEDs).
- **StorageService**: optionally logs energy usage or battery metrics.

## Workflow Example
1. Cold boot → PowerService enables WiFi AP so user can configure schedule.
2. Settings button press → InputService raises `EnableWifiRequested`; PowerService turns on WiFi and keeps the controller awake until WebUiService signals `SessionEnded`.
3. Feed button press → PowerService keeps WiFi off, but ensures servo rail is powered for FeedingService.
4. Before sleep → SystemController calls `power.prepareDeepSleep()` with RTC alarm + button wake sources → `power.enterDeepSleep()`.
5. On RTC wake → `power.onWake()` re-enables servo rail only when FeedingService requests it.

## Testing
- Mock `esp_sleep_*` and WiFi calls to ensure functions are invoked with correct parameters.
- Unit test that servo power toggles align with feeding lifecycle (Power off when idle).
- Validate that enabling AP sets `sleepPending` false to prevent premature sleep.

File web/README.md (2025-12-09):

# Chicken Feeder Web Interface (Vite)

Single Page App for the ESP32 chicken feeder, built with Vite and shipped as static files (ideal for gzipping into a `.h` for the ESP).

## Structure
```
web/
├── index.html          # Vite entry (loads src/main.js)
├── src/
│   ├── main.js         # Bootstraps the app
│   ├── app.js          # UI + API logic
│   └── style.css       # Styling
├── public/
│   └── mock/api.js     # Optional mock API (localStorage)
├── compose.yml         # Dev server via Docker (Vite)
├── vite.config.js
└── package.json
```

## Development (local)
```bash
cd web
npm install
npm run dev -- --host --port 8000
# open http://localhost:8000
```

### Development (Docker)
```bash
cd web
docker compose up        # starts Vite dev server on :8000 (installs deps in container)
```

## Mock API
- Add `?mock=1` to the URL to force the browser mock (`public/mock/api.js`, stored in localStorage).
- Without mock: the app calls `/api/*`. Use the Node mock from the repo root (`docker compose up` there) to provide `/api`.

## Build
```bash
cd web
npm run build            # outputs to web/dist
npm run preview          # optional static preview
```

Feeding guidance (for configuring schedules/portions): see `docs/feeding-guide.md`.

### ESP32 header generation
- `npm run build:esp` (runs Vite build, then `scripts/web-to-header.py dist -o lib/WebService/generated`)
- or `make web-headers` from repo root (does the same).

> Note: The root `docker compose` now serves `web/dist`, so run `npm run build` first if you use it.

## Expected API (real device or Node mock)
```
GET  /api/status
GET  /api/config
POST /api/config
POST /api/config/reset
POST /api/feed
```

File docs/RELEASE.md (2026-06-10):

# Release Process

This document describes how to create and publish a new release of the Automatic Chicken Feeder firmware.

## Prerequisites

- Git repository with clean working directory
- GNU Make installed
- Node.js installed (for web build)
- Python 3 installed (for web-to-header conversion)
- PlatformIO installed
- Optional: Nix with `nix-shell`
- Push access to the GitHub repository

## Release Workflow

### Single Command Release

```bash
make release VERSION=v2.1.0
```

**That's it!** This single command will:

1. ✅ Update `VERSION` file with the version number
2. ✅ Update `web/package.json` version
3. ✅ **Rebuild web interface with new version** (embedded in firmware)
4. ✅ Create a git commit with message "Release vX.X.X"
5. ✅ Create a git tag `vX.X.X`
6. ✅ **Push to GitHub automatically**
7. ✅ **Trigger GitHub Actions Release Build**

**Example Output:**
```
🐔 Starting automated release v2.1.0...

📝 Step 1/5: Updating version files...
✅ Version files updated

🌐 Step 2/5: Building web interface with new version...
✅ Web interface built and embedded

📦 Step 3/5: Committing release...
✅ Release committed

🏷️  Step 4/5: Creating and pushing tag...
✅ Tag v2.1.0 created

🚀 Step 5/5: Pushing to GitHub...
📤 Pushing branch: main
📤 Pushing tag: v2.1.0

✅ ✅ ✅ Release v2.1.0 completed! ✅ ✅ ✅

🔗 GitHub Actions: https://github.com/Friedjof/AutomaticChickenFeeder/actions
🔗 Releases: https://github.com/Friedjof/AutomaticChickenFeeder/releases

⏳ The release build will take ~5-10 minutes
📦 Artifacts: automaticchickenfeeder-v2.1.0.bin, automaticchickenfeeder-v2.1.0.elf
```

### Monitor GitHub Actions

After pushing the tag:
1. Go to: https://github.com/Friedjof/AutomaticChickenFeeder/actions
2. Watch the "Release Build" workflow
3. Wait for completion (~5-10 minutes)

### 5. Verify Release

Once the GitHub Action completes:
1. Go to: https://github.com/Friedjof/AutomaticChickenFeeder/releases
2. You should see the new release `vX.X.X` with:
   - `automaticchickenfeeder-vX.X.X.bin` - Ready for OTA upload
   - `automaticchickenfeeder-vX.X.X.elf` - For debugging
   - Contributor avatars with profile links
   - A linked commit list for all changes since the previous release
   - A full changelog compare link at the bottom

## What Gets Built

The GitHub Action performs these steps:

1. **Checkout code** at the tagged version
2. **Install dependencies** (Node.js, Python, PlatformIO)
3. **Build web interface** (Vite build)
4. **Convert to C headers** (embedded in firmware)
5. **Build firmware** for ESP32-C3
6. **Package binaries** with version suffix
 7. **Generate release notes** from commit history and contributors
 8. **Create GitHub Release** with artifacts

## Release Artifacts

### automaticchickenfeeder-vX.X.X.bin
- **Use for:** OTA updates via web interface
- **How:** Upload via http://192.168.4.1 → Maintenance → Firmware Update
- **Size:** ~500KB - 1MB (depending on features)

### automaticchickenfeeder-vX.X.X.elf
- **Use for:** Debugging with GDB
- **How:** `pio debug --environment esp32c3`
- **Contains:** Symbols for crash analysis

## Build From Release Source ZIP

Every GitHub release page also includes quick build instructions.

### Option A: Regular local toolchain

1. Download **Source code (zip)** from the release page
2. Unzip it
3. Open a terminal in the extracted folder
4. Run:

```bash
make build
```

Requirements:
- GNU Make
- Node.js
- Python 3
- PlatformIO

### Option B: Nix shell

If Nix is available, you can build from the repository root with:

```bash
nix-shell
make build
```

This shell provides the local build tools needed by the repository.

## Partition Table

The firmware uses `min_spiffs.csv` partition scheme:
- **OTA_0:** ~1.9MB (active firmware)
- **OTA_1:** ~1.9MB (update target)
- **SPIFFS:** Minimal (~64KB for NVS config)

This allows seamless OTA updates without USB cable.

## Version Numbering

Follow Semantic Versioning (semver):
- `vMAJOR.MINOR.PATCH`

Examples:
- `v2.0.0` - Major release (breaking changes)
- `v2.1.0` - Minor release (new features)
- `v2.1.1` - Patch release (bug fixes)

## Rollback Procedure

If a release has critical bugs:

1. **Quick fix:** Revert to previous tag
   ```bash
   git revert <commit-hash>
   make release VERSION=v2.1.1
   ```

2. **Emergency:** Users can manually flash older firmware
   ```bash
   pio run -e esp32c3 -t upload
   ```

## Troubleshooting

### GitHub Action fails

**Check logs:**
1. Go to Actions tab
2. Click failed workflow
3. Expand failed step

**Common issues:**
- **Web build fails:** Check `web/package.json` syntax
- **Firmware too large:** Remove debug symbols or optimize code
- **Permission denied:** Check repository settings → Actions → General → Workflow permissions

### Release not appearing

**Verify tag was pushed:**
```bash
git ls-remote --tags origin
```

**Should show:**
```
abc123...  refs/tags/v2.1.0
```

**If missing:**
```bash
git push origin v2.1.0
```

### Can't create tag (already exists)

**Delete local tag:**
```bash
git tag -d v2.1.0
```

**Delete remote tag (DANGEROUS):**
```bash
git push origin :refs/tags/v2.1.0
```

Then re-run `make release`.

## CI/CD Pipeline

```mermaid
graph LR
    A[make release] --> B[Local commit + tag]
    B --> C[GitHub receives tag]
    C --> D[Workflow triggered]
    D --> E[Build firmware]
    E --> F[Create release]
    F --> G[Upload artifacts + release guide]
```

## Best Practices

1. **Always test locally first:**
   ```bash
   make build
   make flash
   # Test all features
   ```

2. **Update CHANGELOG.md** before release

3. **Use descriptive commit messages:**
   - ✅ "Add OTA firmware update feature"
   - ❌ "fix stuff"

4. **Tag format:** Always use `v` prefix (e.g., `v2.1.0`, not `2.1.0`)

5. **Pre-release testing:**
   - Test on actual hardware
   - Verify OTA update works
   - Check deep sleep behavior
   - Confirm RTC scheduling

## Emergency Hotfix

For critical production bugs:

```bash
# From main branch
git checkout -b hotfix/v2.0.1
# Fix the bug
git commit -m "Fix critical feeding bug"
make release VERSION=v2.0.1
# Merge back
git checkout main
git merge hotfix/v2.0.1
git push origin main
```

## Release Checklist

Before creating a release:

- [ ] All tests pass locally
- [ ] Web interface works in browser
- [ ] OTA update tested
- [ ] Deep sleep tested
- [ ] RTC scheduling verified
- [ ] Documentation updated
- [ ] CHANGELOG.md updated
- [ ] Version number decided
- [ ] Clean git status (`git status`)

After release:

- [ ] GitHub Action completed successfully
- [ ] Release appears on GitHub
- [ ] Binaries downloadable
- [ ] Release notes look correct
- [ ] Test OTA update from release binary

## Support

For issues with releases:
- Open issue: https://github.com/Friedjof/AutomaticChickenFeeder/issues
- Check Actions logs: https://github.com/Friedjof/AutomaticChickenFeeder/actions
- Review release docs: `docs/RELEASE.md`

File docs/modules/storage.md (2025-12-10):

# Config Service (Storage & Persistence)

## Purpose
The ConfigService manages all persistent configuration using ESP32's NVS (Non-Volatile Storage). It provides a simple key-value interface for schedules, settings, and feed history that survives deep sleep and power cycles.

## Hardware Platform
- **ESP32-C3** (Seeed XIAO ESP32C3)
- **NVS Partition**: Flash-based key-value storage
- **Namespace**: "feeder"

## Storage Medium
Uses ESP32 `Preferences` library (NVS wrapper):
- Key-value pairs stored in flash
- Survives deep sleep and power cycles
- Wear-leveling built into NVS
- No filesystem overhead (LittleFS not used)

## Responsibilities
- Load and save feed schedules (6 slots)
- Manage portion unit configuration (grams per unit)
- Persist feed history (last 10 feeds)
- Provide factory reset functionality
- Ensure data integrity across power cycles

## Data Structures

### Schedule Entry
```cpp
struct Schedule {
    uint8_t id;              // 1-6
    bool enabled;            // Active/inactive
    char time[6];            // "HH:MM" format
    uint8_t weekday_mask;    // Bit 0=Sunday, 6=Saturday
    uint8_t portion_units;   // 1-5 units per feed
};
```

### Feed History Entry
```cpp
struct FeedHistoryEntry {
    uint32_t timestamp;      // Unix timestamp
    uint8_t portion_units;   // Total portions fed
};
```

## Configuration Parameters

### Constants
- `MAX_SCHEDULES`: 6 feed schedule slots
- `MAX_FEED_HISTORY`: 10 historical feed entries
- Default portion size: 12g per unit

### NVS Keys
| Key | Type | Description |
|-----|---|---|
| `sched_0` ... `sched_5` | String (JSON) | Individual schedule entries |
| `portionGrams` | UChar | Grams per portion unit (default 12) |
| `feedHist` | Bytes | Binary blob of feed history |
| `feedHistCnt` | UChar | Number of valid history entries |

## Public API

```cpp
// Lifecycle
bool begin();  // Initialize NVS, load defaults

// Schedule management
bool loadSchedule(uint8_t index, Schedule &schedule);
bool saveSchedule(uint8_t index, const Schedule &schedule);
bool loadAllSchedules(Schedule schedules[MAX_SCHEDULES]);
bool saveAllSchedules(const Schedule schedules[MAX_SCHEDULES]);

// Portion configuration
uint8_t getPortionUnitGrams();
void setPortionUnitGrams(uint8_t grams);

// Feed history
bool saveFeedHistory(const FeedHistoryEntry* history, uint8_t count);
uint8_t loadFeedHistory(FeedHistoryEntry* history, uint8_t maxCount);
bool clearFeedHistory();

// Factory reset
bool resetToDefaults();
```

## Schedule Storage Format

Schedules are stored as JSON strings for flexibility:
```json
{
  "id": 1,
  "enabled": true,
  "time": "06:30",
  "weekday_mask": 62,
  "portion_units": 2
}
```

**Weekday Mask Encoding:**
- Bit 0 = Sunday
- Bit 1 = Monday
- ...
- Bit 6 = Saturday
- Example: 62 (0b0111110) = Monday–Friday

## Feed History Storage

Stored as binary blob for efficiency:
- Array of `FeedHistoryEntry` structs
- Size: `count * sizeof(FeedHistoryEntry)` bytes
- Separate counter stores number of valid entries
- Loaded at startup, saved before deep sleep

## Default Configuration

Factory defaults (applied on first boot or reset):
```cpp
Schedule defaults[6] = {
    {1, false, "06:30", 62, 1},  // Mon-Fri 6:30am, 1 unit
    {2, false, "12:00", 62, 1},  // Mon-Fri 12:00pm, 1 unit
    {3, false, "18:00", 62, 1},  // Mon-Fri 6:00pm, 1 unit
    {4, false, "22:00", 62, 1},  // Mon-Fri 10:00pm, 1 unit
    {5, false, "00:00", 0, 1},   // Disabled
    {6, false, "00:00", 0, 1}    // Disabled
};
portion_unit_grams = 12;
```

## Integration Points

### Main Application
- `begin()` called during setup to initialize NVS
- Feed history loaded at startup, saved before sleep

### SchedulingService
- Loads schedules on initialization
- Calls `saveAllSchedules()` after API updates
- Triggers schedule regeneration after changes

### FeedingService
- Queries `getPortionUnitGrams()` for gram calculations
- Provides feed history data for persistence

### WebService
- API calls trigger schedule saves
- Returns portion unit grams in status responses
- Serves feed history via `/api/status/history`

## Error Handling
- Missing keys return default values
- Invalid JSON triggers default schedule creation
- NVS failures logged to serial, operation continues with defaults
- `begin()` returns false only on critical NVS init failure

## Data Validation
- Portion units clamped to 1-5 range
- Time format validated (HH:MM)
- Weekday mask within valid range (0-127)
- Schedule index bounds checked (0-5)

## Flash Endurance
- NVS uses wear-leveling automatically
- Schedules saved only on explicit API calls
- Feed history saved once per sleep cycle
- Typical writes: <10 per day under normal usage
- NVS flash blocks rated for 10,000+ cycles

## Factory Reset
Triggered via `resetToDefaults()`:
1. Restore default schedules (all disabled except presets)
2. Reset portion unit grams to 12g
3. Clear all feed history
4. Logs reset completion to serial

## Testing
- Serial output shows NVS operations
- Monitor `[CONFIG]` log prefix for debug info
- Verify persistence across power cycles
- Test factory reset via API or serial command

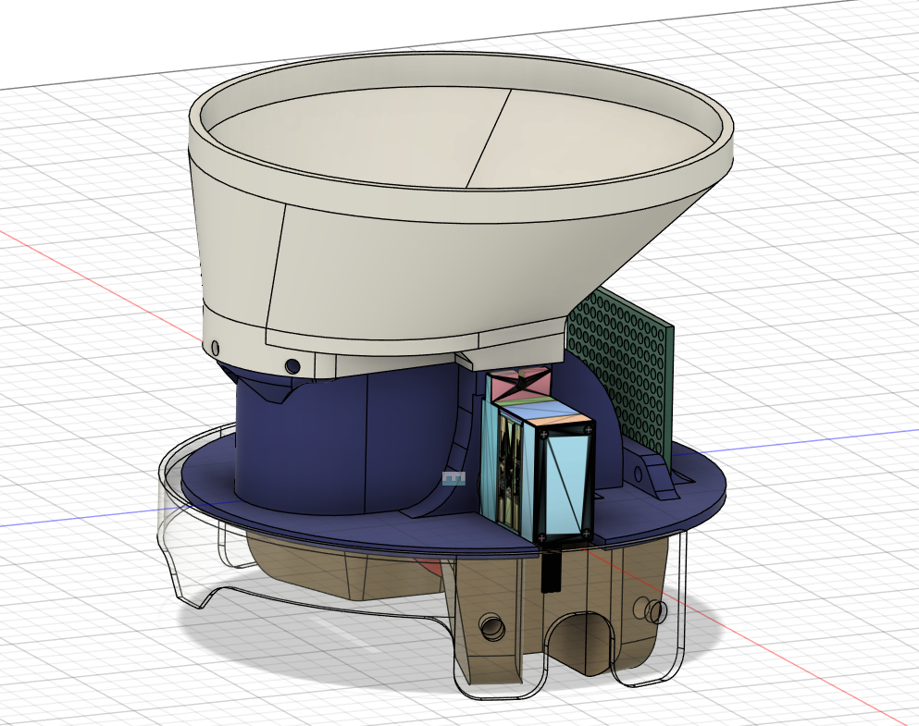
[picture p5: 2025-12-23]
media/images/3d-side-static.png

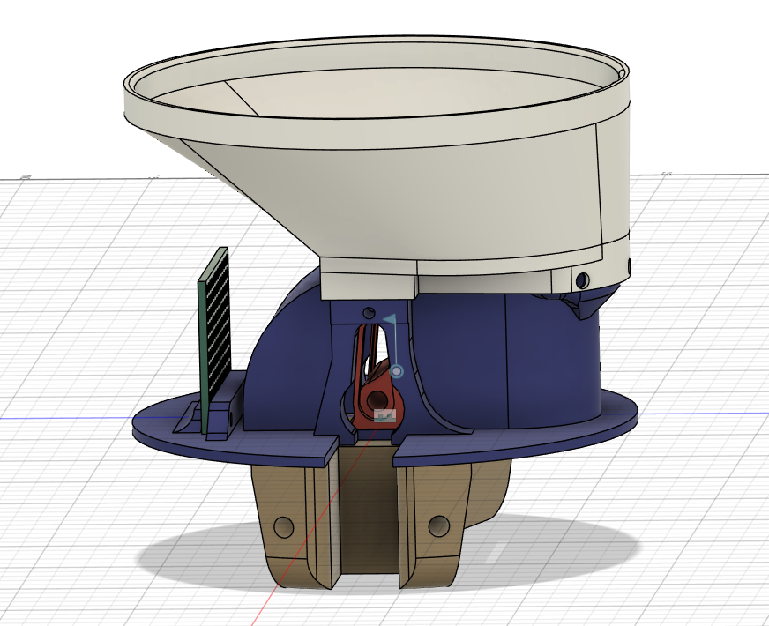
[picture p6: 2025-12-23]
media/images/3d-side-motor-static.png

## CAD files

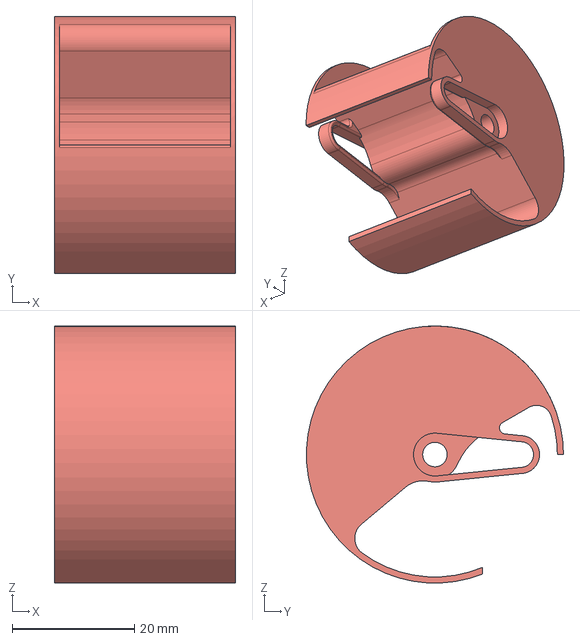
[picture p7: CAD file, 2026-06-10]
media/3d/schaufel.step
29.6 x 42.0 x 42.0 mm

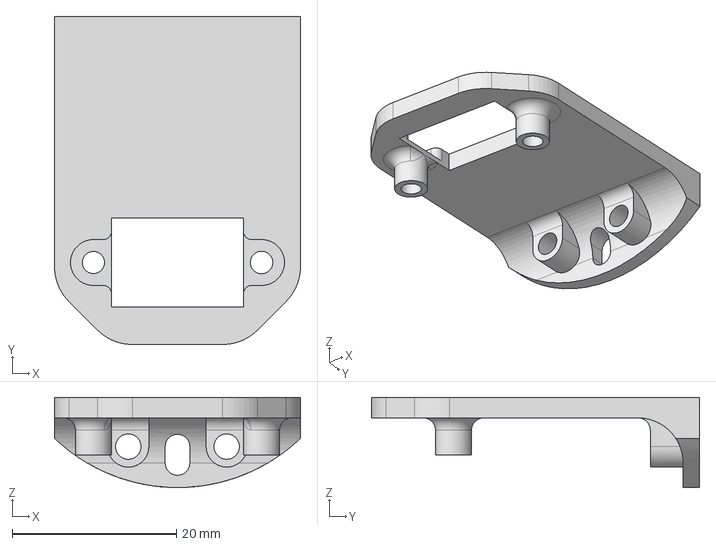
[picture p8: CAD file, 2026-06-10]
media/3d/lichtschranke.step
30.0 x 40.0 x 11.0 mm

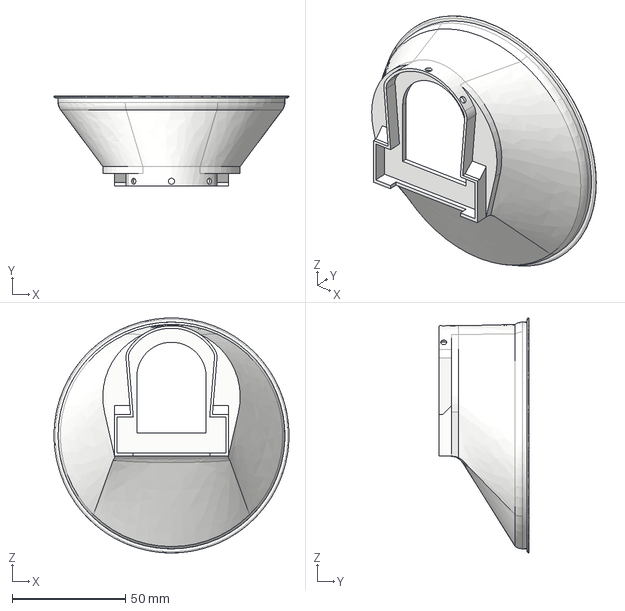
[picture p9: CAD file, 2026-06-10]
media/3d/trichter.step
103.6 x 39.5 x 103.6 mm

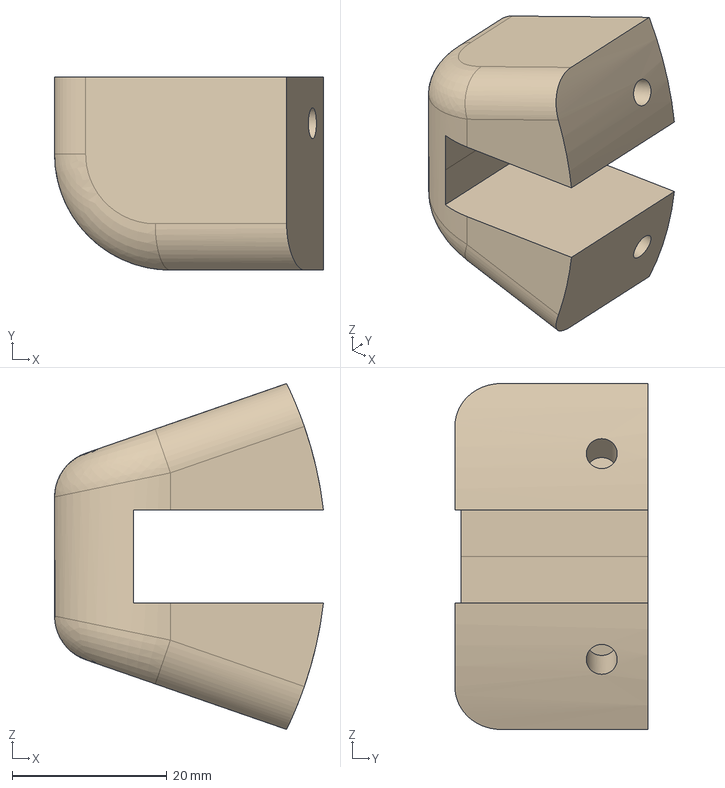
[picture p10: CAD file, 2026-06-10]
media/3d/fix.step
34.8 x 25.0 x 44.8 mm

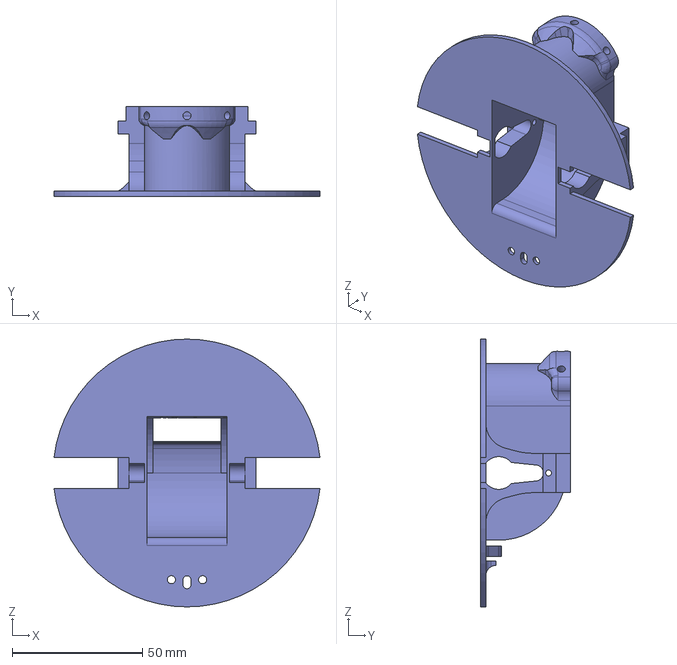
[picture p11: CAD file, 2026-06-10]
media/3d/base.step
102.2 x 34.5 x 102.9 mm

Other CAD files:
media/3d/base.stl
media/3d/fix.stl
media/3d/lichtschranke.stl
media/3d/schaufel.stl
media/3d/trichter.stl

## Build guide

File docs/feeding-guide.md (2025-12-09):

# Chicken Feeding Guide (freerange-oriented)

Quick facts and recommended defaults for the automatic feeder. Values assume 2.0–2.5 kg freerange hens with good outdoor access.

## Daily intake
- Freerange hens self-forage 20–50%; target **80–120 g complete feed per day** (up to ~130 g for high layers).
- Winter: +10–20% for warmth. Small breeds/chicks need less; adjust per weight.

## Feed choice
- Use **layer/land hen complete feed** (~16% protein, 3.5–4% calcium, grain base ~60%, plant protein ~20%, fiber).
- Always provide grit (gastroliths) and oyster shell free choice.
- Keep raw fruit/veg treats under 10% of ration to avoid diluting nutrients.

| Feed type | Typical composition | Fits for |
| --- | --- | --- |
| Layer meal/mash| ~60% grain, ~20% protein, ~4% Ca | Freerange layers (main feed)  |
| Grain mix | Cracked corn, oats, rye | Supplemental scratch in run |
| Complete feed  | 16% protein, ~11 MJ/kg ME | Main hopper/automatic feeder  |

## Feeding times (automated)
- **2–3 drops/day**:  
  - Morning pre-range: 60–70% of daily ration around sunrise.  
  - Midday: small top-up ~3 h later.  
  - Evening: small top-up after laying, before dusk.
- Prefer short block feedings; avoid leaving full troughs all day (reduces selective picking).
- Sync timers to sunrise/sunset (e.g., Munich: ~8:00 winter, ~5:00 summer); add ~20% in winter.

## Software tips for the feeder
- **Portions**: Start with 40–60 g morning, 20–30 g noon/evening; let users adjust per flock size/weight.
- **Timers**: Support location-based sunrise times + seasonal multiplier (+20% winter). Consider a “daily empty” check via weight sensor to prevent stale feed.
- **Onboarding**: First week allow manual scatter, vary amounts; add humidity alert for feed spoilage risk.
- **Monitoring**: Track daily intake toward 120 g/hen; warn below ~80 g. Optionally correlate with lay rate to nudge portions up for high performers.

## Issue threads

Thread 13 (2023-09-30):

Change the file system from esp32dev from SPIFFS to littlefs

Friedjof, 2023-09-30:
SPIFFS is deprecated and should be replaced. The platformio.ini must also be adapted for this (see esp8266).

Closed 2023-09-30.

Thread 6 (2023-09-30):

add hostname (dns) and subnetmask to config.json

Friedjof, 2023-09-30:
## Explanation
So that the configuration interface can also be accessed via a local domain, another configuration `hostname` and `subnetmask` could be added to `config.json` under `wifi`. This also creates further transparency as to how exactly the configuration interface can be called up.
## Todo
For this, the `config.json(-template)`, the `ConfigManager` (save, load and the wifi type), the `main.cpp` (wifi config and such), as well as the documentation (`README.md`) must be adapted.

Friedjof, 2023-09-30:
A lib must be added for DNS (see https://community.platformio.org/t/how-to-include-arduino-library-in-platformio/15146). There is a very good example for this: https://techtutorialsx.com/2020/04/17/esp32-mdns-address-resolution/

Friedjof, 2023-09-30:
It is not as simple as we thought. So far I have added the MDNS library and adapted the configuration file accordingly. One could still fix the TODO in the main.cpp so that the ip, subnet and gateway can be set via config.json. But that has not worked for me so far. Unfortunately, I don't know exactly why. More about this in the [TODO](https://github.com/Friedjof/automatic-chicken-feeder/blob/6-dns-and-subnetmask/src/main.cpp#L186.)

Friedjof, 2023-09-30:
And we still have to see how far we have to adapt it for the esp8266. But maybe that's not so important for now. Just develop it for the esp32 first and then see what happens.

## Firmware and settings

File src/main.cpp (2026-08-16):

#include <Arduino.h>
#include <esp_sleep.h>

#include "FeedingService.hpp"
#include "ButtonService.hpp"
#include "ClockService.hpp"
#include "ConfigService.hpp"
#include "WebService.hpp"
#include "SchedulingService.hpp"
#include "VibrationService.hpp"
#include "PinConfig.h"

// Power management
static const uint32_t INACTIVITY_SLEEP_MS = 120000;  // 2 minutes
static const uint32_t MAINTENANCE_TIMEOUT_MS = 15UL * 60UL * 1000UL;  // 15 minutes without web activity

void simpleClickHandler(Button2 &btn);
void doubleClickHandler(Button2 &btn);
void longClickHandler(Button2 &btn);
void enterDeepSleep(const char* reason);
void markActivity();
void handleSleepLogic();

// Services
ButtonService buttonService;
FeedingService feedingService;
ClockService clockService;
ConfigService configService;
VibrationService vibrationService;
SchedulingService schedulingService(configService, clockService, feedingService);
WebService webService(configService, clockService, feedingService, schedulingService, vibrationService);

// State flags
bool wokeFromRtcAlarm = false;
bool wokeFromButton = false;
bool wokeFromPowerOn = false;
unsigned long lastActivityMillis = 0;
unsigned long ignoreButtonUntil = 0;

void setup() {
  Serial.begin(115200);
  delay(1000);

  // Subscribe the main loop task to the framework's already-running task
  // watchdog (CONFIG_ESP_TASK_WDT, 10s timeout) - our only safety net against
  // an unforeseen hang during years of unattended operation.
  enableLoopWDT();

  Serial.println("\n\n[INFO] ========================================");
  Serial.println("[INFO] Automatic Chicken Feeder v2.0");
  Serial.println("[INFO] ========================================\n");

  // Configure sleep callback for web API
  webService.setSleepCallback([]() { enterDeepSleep("Remote request"); });
  feedingService.setClockService(&clockService);
  feedingService.setConfigService(&configService);
  feedingService.setVibrationService(&vibrationService);

  // Wake cause detection
  esp_sleep_wakeup_cause_t wakeupReason = esp_sleep_get_wakeup_cause();
  uint64_t gpioStatus = esp_sleep_get_gpio_wakeup_status();

  if (wakeupReason == ESP_SLEEP_WAKEUP_GPIO) {
    if (gpioStatus & (1ULL << RTC_INT_PIN)) {
      wokeFromRtcAlarm = true;
      Serial.println("[INFO] Wake reason: RTC alarm (GPIO)");
    }
    if (gpioStatus & (1ULL << BUTTON_PIN)) {
      wokeFromButton = true;
      Serial.println("[INFO] Wake reason: Button (GPIO)");
    }
  } else {
    wokeFromPowerOn = true;
    Serial.println("[INFO] Wake reason: Power-on reset or unknown");
  }

  // Check for maintenance mode (button held during boot)
  pinMode(BUTTON_PIN, INPUT_PULLUP);
  delay(50);  // Debounce
  bool maintenanceModeRequested = (digitalRead(BUTTON_PIN) == LOW);

  markActivity();

  // Initialize config service
  if (!configService.begin()) {
    Serial.println("[ERROR] Failed to initialize ConfigService!");
  }

  // Initialize clock service
  if (!clockService.begin()) {
    Serial.println("[WARN] DS3231 RTC not available - time sync required");
  }

  // Load feed history from persistent storage
  FeedHistoryEntry history[MAX_FEED_HISTORY];
  uint8_t historyWriteIndex = 0;
  uint8_t historyCount = configService.loadFeedHistory(history, MAX_FEED_HISTORY, historyWriteIndex);
  if (historyCount > 0) {
    feedingService.loadFeedHistory(history, historyCount, historyWriteIndex);
  }

  // Initialize button service
  buttonService.begin();
  buttonService.setSimpleClickHandler(simpleClickHandler);
  buttonService.setDoubleClickHandler(doubleClickHandler);
  buttonService.setLongClickHandler(longClickHandler);

  // Initialize feeding service
  feedingService.setup();

  // Initialize scheduling service
  schedulingService.begin();

  // Start web server
  if (!webService.begin()) {
    Serial.println("[ERROR] Failed to start WebService!");
  }

  // MAINTENANCE MODE CHECK
  if (maintenanceModeRequested) {
    Serial.println("\n[MAINTENANCE] ========================================");
    Serial.println("[MAINTENANCE] Entering MAINTENANCE MODE");
    Serial.println("[MAINTENANCE] OTA updates enabled");
    Serial.println("[MAINTENANCE] WiFi AP will stay active");
    Serial.println("[MAINTENANCE] No automatic sleep");
    Serial.println("[MAINTENANCE] ========================================\n");

    // Enable maintenance mode in WebService
    webService.setMaintenanceMode(true);

    // Start AP mode for OTA access
    webService.startAP("ChickenFeeder", "");

    // Infinite loop for maintenance mode - no sleep
    Serial.println("[MAINTENANCE] Ready for OTA updates");
    Serial.println("[MAINTENANCE] Connect to WiFi: ChickenFeeder");
    Serial.println("[MAINTENANCE] Open browser: http://192.168.4.1");
    Serial.println("[MAINTENANCE] Navigate to Maintenance section for firmware upload\n");

    while (true) {
      feedLoopWDT();
      webService.update();
      feedingService.update();
      vibrationService.update();
      schedulingService.update();

      if ((unsigned long)(millis() - webService.getLastClientActivity()) > MAINTENANCE_TIMEOUT_MS) {
        Serial.println("[MAINTENANCE] No activity for 15 minutes - rebooting to normal operation");
        delay(100);
        ESP.restart();
      }

      delay(10);
    }
  }

  // Handle wake-specific actions
  if (wokeFromRtcAlarm) {
    // Process due events immediately (DS3231 alarm line stays low until cleared)
    schedulingService.checkAlarm();
  }

  if (wokeFromButton) {
    Serial.println("[BUTTON] Woke from button - AP will start shortly");

    // Ignore button events for 2 seconds to avoid consuming wakeup press
    ignoreButtonUntil = millis() + 2000;

    // Wait a short moment before starting AP (give button time to settle;
    // Button2's own debounce is only 50ms, so this just needs a small margin)
    delay(150);

    // Start AP mode
    Serial.println("[BUTTON] Starting AP mode");
    webService.startAP("ChickenFeeder", "");

    // Mark activity to prevent immediate sleep
    markActivity();
  }

  if (wokeFromPowerOn) {
    Serial.println("[BOOT] Cold boot - starting AP mode automatically");
    webService.startAP("ChickenFeeder", "");
    markActivity();
  }

  Serial.println("\n[INFO] Setup complete.");
  Serial.println("[INFO] Press button once to start AP mode");
  Serial.println("[INFO] Press button twice to feed manually");
  Serial.println("[INFO] Long press button to enter deep sleep");
  Serial.println("[INFO] OTA updates available via web interface when AP is active");
}

void loop() {
  feedLoopWDT();
  buttonService.loop();
  feedingService.update();
  webService.update();
  schedulingService.update();
  vibrationService.update();
  handleSleepLogic();
}

void simpleClickHandler(Button2 &btn) {
  // Always mark activity (reset sleep timer), even if ignoring the click action
  markActivity();

  // Ignore button events if we're in the ignore window (after wakeup)
  if (millis() < ignoreButtonUntil) {
    Serial.println("[BUTTON] Ignoring single click (too soon after wakeup) - but timer reset");
    return;
  }

  Serial.println("[BUTTON] Single click - Starting AP mode");
  webService.startAP("ChickenFeeder", "");
}

void doubleClickHandler(Button2 &btn) {
  // Always mark activity (reset sleep timer), even if ignoring the click action
  markActivity();

  // Ignore button events if we're in the ignore window (after wakeup)
  if (millis() < ignoreButtonUntil) {
    Serial.println("[BUTTON] Ignoring double click (too soon after wakeup) - but timer reset");
    return;
  }

  Serial.println("[BUTTON] Double click - Manual feed");
  feedingService.feed(configService.getManualPortionUnits());
}

void longClickHandler(Button2 &btn) {
  Serial.println("[BUTTON] Long click - Entering deep sleep");
  enterDeepSleep("Manual long press");
}

void markActivity() {
  lastActivityMillis = millis();
}

void handleSleepLogic() {
  unsigned long now = millis();

  // Skip sleeping while feeding
  if (feedingService.isFeeding()) {
    markActivity();
    return;
  }

  // Skip sleeping while the post-feed vibration tail is still running
  // (feed can finish and isFeeding() go false before the tail winds down)
  if (vibrationService.isActive()) {
    markActivity();
    return;
  }

  // Keep awake while AP is active
  if (webService.isAPActive()) {
    return;
  }

  // After RTC alarm wake, go back to sleep once work is done
  if (wokeFromRtcAlarm) {
    enterDeepSleep("RTC alarm handled");
    return;
  }

  // Inactivity-based sleep
  uint32_t lastClient = webService.getLastClientActivity();
  uint32_t lastActivity = max(lastActivityMillis, lastClient);

  if ((now - lastActivity) >= INACTIVITY_SLEEP_MS) {
    enterDeepSleep("Inactivity timeout");
  }
}

void enterDeepSleep(const char* reason) {
  Serial.printf("[SLEEP] Entering deep sleep: %s\n", reason);

  // Save feed history to persistent storage before sleeping
  uint8_t historyCount = feedingService.getFeedHistoryCount();
  if (historyCount > 0) {
    configService.saveFeedHistory(feedingService.getFeedHistory(), historyCount, feedingService.getFeedHistoryWriteIndex());
  }

  // Ensure AP is stopped if it was running
  webService.stopAP();

  // Configure wake sources (active-low alarm/button)
  pinMode(RTC_INT_PIN, INPUT_PULLUP);
  pinMode(BUTTON_PIN, INPUT_PULLUP);

  const uint64_t wakeMask = (1ULL << RTC_INT_PIN) | (1ULL << BUTTON_PIN);
  esp_deep_sleep_enable_gpio_wakeup(wakeMask, ESP_GPIO_WAKEUP_GPIO_LOW);

  Serial.flush();
  esp_deep_sleep_start();
}

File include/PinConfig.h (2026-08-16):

#pragma once

#define RTC_INT_PIN 3
#define BUTTON_PIN 4
#define SERVO1_PIN 21
#define SERVO2_PIN 2
#define TRANSISTOR_PIN 5
#define VIBRATION_PIN 10

// Set to 0 (e.g. via `-D VIBRATION_MOTOR_ENABLED=0` in platformio.ini) on
// hardware builds that don't have a vibration motor wired up - VibrationService
// then never touches VIBRATION_PIN and the web UI hides the related controls.
#ifndef VIBRATION_MOTOR_ENABLED
#define VIBRATION_MOTOR_ENABLED 1
#endif

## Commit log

2023-09-30 add: build esp32dev cicd
2023-09-30 test: this build will fail
    [main.cpp]
2023-09-30 fix: test issue in main.cpp
    [main.cpp]
2023-10-15 fix: esp8266 build process
    [main.cpp]
2024-02-19 add: support for esp32s3
2024-02-20 add: esp32 images
2024-02-20 fix: esp32s3 support
2024-02-20 ref: hole readme
2024-05-22 fix: logging in main
    [main.cpp]
2024-05-22 fix: add to as
    [main.cpp]
2025-07-06 fix: improve logging and RTC error messages; update upload port and board settings
    [main.cpp]
2025-07-24 Add Product Requirements Document and user stories for Automated Chicken Feeder
    - Created a comprehensive Product Requirements Document (PRD) outlining the objectives, user stories, functional and non-functional requirements, constraints, and acceptance criteria for the Automate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
    - Added user stories detailing hardware setup, manual feeding control, sensor integration, and scheduling system.
    - Implemented a basic web dashboard foundation for remote monitoring and control of the feeding system.
    - Refactored main application to integrate feeding component and removed obsolete servo library dependency.
2025-07-24 feat: implement manual feeding control with button input and servo power management
2025-07-25 feat: update README and circuit diagrams with detailed pin assignments and power control information for manual feeding system
2025-08-18 feat: update README, circuit diagrams, and troubleshooting guide for servo power control; refactor feeding component for improved PWM handling and state management
2025-08-25 Implement RTC and Scheduler Services for Feeding Management
    - Added RTC driver for DS3231 integration, including time and temperature management, alarm functionality, and I2C communication.
    - Developed Scheduler service to manage feeding schedules, including adding, removing, and processing schedules with persistent storage in NVS.
    - Created time management utilities for validating and formatting time and date.
    - Documented RTC and Scheduler services, detailing API, features, and implementation specifics.
2025-12-09 feat: initialize web application with Vite, mock API, and main app logic
    - Created package.json for project dependencies and scripts
    - Added mock API implementation to simulate ESP32 responses
    - Developed main application logic for the Chicken Feeder web interface
    - Implemented user interface styles with CSS
    - Configured Vite for development and production builds
2025-12-09 feat: update README and AGENTS documentation, enhance button control logic, and adjust servo pin assignments
2025-12-09 Update footer button text from "Shut down & sleep" to "Take a Nap"
2025-12-10 Refactor input, scheduling, storage, and web UI modules for improved functionality and clarity
    - Updated Input Service to Button Service with enhanced gesture recognition and debouncing features.
    - Redesigned Scheduling Service to manage RTC alarms and event generation for feeding schedules.
    - Revamped Config Service for better configuration handling and persistence using ESP32's NVS.
    - Overhauled Web Service to provide a responsive UI and REST API for configuration and manual control.
    - Added comprehensive testing strategies and improved logging across modules for better diagnostics.
2025-12-19 feat: Enhance feeding service and UI improvements
    - Added configuration service to feeding service in main.cpp for better management.
    - Updated HTML to collapse the feeding guide section by default and changed button text to "Show guide".
    - Improved feed history loading in app.js by sorting feeds by timestamp (newest first) and handling empty/error states more gracefully.
    [main.cpp]
2025-12-23 feat: implement stepwise servo movement for smooth operation
    - Add STEP_SIZE (30°) and STEP_DELAY (50ms) constants
    - Introduce currentStepPosition variable for incremental movement
    - Refactor MOVING state to move servos in small steps
    - Ensure synchronous movement of both servos
    - Improve debug logging for movement tracking
    This change prevents abrupt servo movements and provides smoother
    opening/closing of the feeding mechanism.
2025-12-23 feat(web): add mobile smart timer view
    - Add Smart View toggle button below portion input
    - Implement auto-sorting: enabled timers appear first
    - Show/hide timers based on enabled count (mobile only)
    - Desktop: always show all timers in original order
    - Mobile Smart View: show enabled timers + 1 disabled (min 2, max 6)
    - Add comprehensive debug logging for troubleshooting
    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
2025-12-23 style(web): improve UI animations and transitions
    - Replace expand button rotation with subtle border animation
    - Expanded state: thicker blue border (2.5px) instead of color fill
    - Add smooth transitions for timer visibility (opacity, transform, height)
    - Implement Smart View toggle button styling (mobile only)
    - Full-width expand button on mobile (flex: 1)
    - Update embedded web files (web_files.h)
    These changes provide more professional and intuitive visual feedback
    while maintaining clarity across all device sizes.
2025-12-23 docs: add 3D design section and update features
    - Add 3D Design showcase with animation and static views
    - Cross-section view showing internal mechanics
    - Animated rotating view (GIF)
    - Top view showing overall layout
    - Document new Mobile-Optimized UI feature
    - Add media/pcb/ to .gitignore
    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
2025-12-23 docs: add note about upcoming 3D printable models
2025-12-25 fix: update step delay for smoother servo movement
2026-06-03 feat: show device time and handle Europe/Berlin DST
2026-06-06 fix: improve device time layout and update screenshots
2026-06-06 fix: correct feed history routing and persistence
    [main.cpp]
2026-06-10 add(3d): add the 3d models
    [base.step, base.stl, fix.step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]
2026-08-16 feat: add vibration motor to counter clumped feed pellets
    [main.cpp]
2026-08-16 feat: add vibration motor settings to the web UI
2026-08-16 fix: improve WiFi AP startup reliability
    [main.cpp]
2026-08-16 refactor: centralize pin definitions and library manifests
2026-08-16 build: pin platformio espressif32 platform to a known-good version
2026-08-16 docs: correct button mapping, gpio table and add missing services
2026-08-16 fix: harden rtc against lost power and silent alarm write failures
2026-08-16 fix: abort feed cycle when servo attach fails
2026-08-16 fix: bound maintenance mode and enable watchdog for hang recovery
    [main.cpp]
2026-08-16 feat: make vibration motor optional via build flag
    [PinConfig.h]
